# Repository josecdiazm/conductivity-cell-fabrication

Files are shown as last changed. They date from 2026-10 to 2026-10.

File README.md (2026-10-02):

# Conductivity Cell Fabrication

Fabrication resources for ionic conductivity cells, covering both manual (by-hand) construction and PCB-based fabrication.

| In-plane cell (hand) | In-plane cell (PCB) | Through-plane cell (PCB) |
|---|---|---|
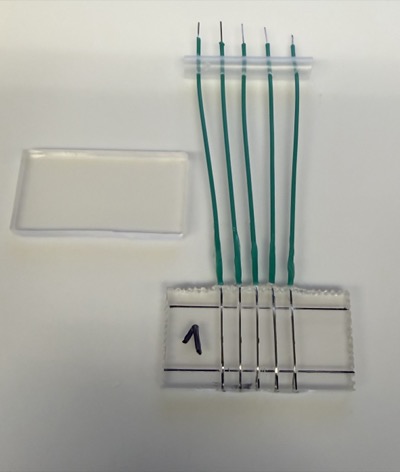
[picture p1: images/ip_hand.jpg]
In-plane cell, hand-fabricated
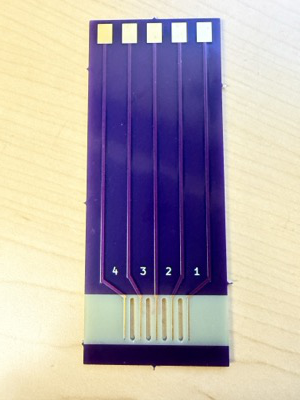
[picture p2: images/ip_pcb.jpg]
In-plane cell, PCB
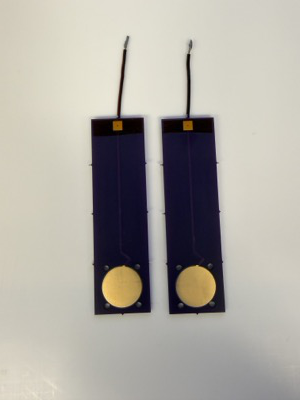
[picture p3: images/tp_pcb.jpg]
Through-plane cell, PCB
|  |  |  |

## Contents

- `manuals/Fabrication_Manual_for_In_Plane_Ionic_Conductivity_Cell.pdf` — step-by-step manual for fabricating in-plane ionic conductivity cells by hand.
- `manuals/KiCad_for_Conductivity_Cell_Design.pdf` — manual for designing and fabricating conductivity cells as PCBs using KiCad.
- `pcb_designs/TP_cell/` — KiCad project and gerber files for the through-plane (TP) cell design.
- `pcb_designs/IP_cell_long-holes/` — KiCad project and gerber files for the in-plane (IP), long-holes cell design.

## PCB designs

Each folder under `pcb_designs/` contains the full KiCad project (`.kicad_pro`, `.kicad_pcb`, `.kicad_sch`) plus a `gerber`/`gerbers` folder with manufacturing files ready to submit to a PCB fab.

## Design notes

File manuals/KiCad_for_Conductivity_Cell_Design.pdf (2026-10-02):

## KiCad for Conductivity Cell Design

José Díaz-Milhet, PhD
Postdoc at MWET (UT Austin) and LBNL-ALS

October 2, 2026

Printed circuit boards (PCBs) make excellent, inexpensive and highly reproducible electrode substrates for electrochemical measurements: the electrode geometry is defined by lithography to within tens of micrometers, the exposed pads can be gold-plated, and a batch of identical cells costs a few dollars. This guide shows how to download and install KiCad, a free and open-source PCB design suite, explains the handful of concepts needed to draw a simple electrode board, and walks through two worked examples: a through-plane and an in-plane cell for measuring the ionic conductivity of membranes.

## Contents

1 Why Use a PCB as an Electrochemical Cell? | 2
2 Downloading and Installing KiCad | 2
3 PCB Primer | 2
4 Step by Step Small Workflow | 4
5 Example 1: Through-Plane Conductivity Cell | 5
6 Example 2: In-Plane Conductivity Cell | 6
7 Ordering Boards | 7
8 Further Reading | 8

## 1 Why Use a PCB as an Electrochemical Cell?

A conductivity cell needs electrodes of accurately known geometry, a rigid flat support and reliable connections to the potentiostat. A PCB provides all three:

- Defined geometry. Electrode area and spacing—the quantities that enter the cell constant—are set by the manufacturer’s photolithography, not by hand.
- Inert surface. With an ENIG (electro-less nickel immersion gold) finish, all exposed copper is covered by nickel and a thin layer of gold.
- Built-in insulation. The solder mask covers the traces, so only the electrode and the contact pad touch the sample or the clips.
- Low cost and reproducibility. Boards are ordered in batches, so every lab member, or every collaborating lab, can use an identical cell.

KiCad is well suited to this job because it is free, runs on Windows, macOS and Linux, and its native files are accepted directly by several board manufacturers.

## 2 Downloading and Installing KiCad

KiCad is distributed from its official site, https://www.kicad.org/download/. Always download from there. This guide was written for KiCad 10 (version 10.0.6, the stable release in October 2026); versions 8 and 9 look and behave almost identically.

First launch. KiCad asks whether to import settings from an earlier version or start with defaults (choose defaults on a new machine), and how to set up the global symbol and footprint library tables. Choose the recommended option, which copies the default tables, so that the standard libraries (including the mounting-hole footprints used below) are available.

## 3 PCB Primer

### 3.1 The project manager and its tools

Opening KiCad shows the project manager. A project is a folder containing a project file (.kicad_pro), a schematic (.kicad_sch) and a board layout (.kicad_pcb). The tools that matter here are:

Tool | What it is for
PCB Editor | Drawing the physical board: outline, copper, mask openings, holes. This is where
almost all the work for an electrode board happens. Footprint Editor Creating reusable pads and holes (e.g. a disc electrode or a slot) that can be placed on any board.
Schematic Editor | Drawing the electrical circuit. Optional for a simple electrode board (Section 4.1).
Gerber Viewer | Checking the exported manufacturing files before ordering.

### 3.2 Layers

A board is described as a stack of layers, selected in the Appearance panel on the right of the PCB Editor. Whatever you draw goes on the active layer (marked by a small arrow in the list). Only a few layers matter for an electrode board (Table 1 and Fig. 1).

Table 1: The layers used for an electrode board.

Layer | Meaning
F.Cu, B.Cu | Copper on the front and back. Pads, electrodes and tracks.
F.Mask, B.Mask | Solder mask. Negative: a shape drawn here is an opening in the
| mask, i.e. exposed (gold-plated) metal.
Edge.Cuts | Board outline and internal cut-outs. Must be closed shapes.
F.Silkscreen, B.Silkscreen | Printed labels (electrode numbers, version, date).
User.Drawings, User.Comments | Notes and dimensions for yourself; not manufactured.

FR4 substrate, ≈1600 µm (1.6 mm)

exposed pad
Cu ≈35 µm
+ Ni 3–6 µm
+ Au 0.05–0.1 µm

solder mask
≈15–25 µm

track
Cu ≈35 µm,
under mask

silkscreen
≈20 µm

Figure 1: Cross-section of a board (not to scale) with typical layer thicknesses for a standard 1 oz copper, ENIG-finished board. The solder mask covers everything except where a shape has been drawn on the mask layer; the surface finish is applied only to exposed copper. Exact values vary by manufacturer.

### 3.3 Units and grid

Work in mm: toggle units with the mm button on the left toolbar or Ctrl + U . Choose a grid from the drop-down list in the top toolbar (e.g. 0.5 mm); everything you draw snaps to it, which makes symmetric layouts easy. The status bar at the bottom shows the absolute cursor position and the distance (dx, dy, dist) from a local origin that you reset by pressing Space . This is the quickest way to measure electrode spacing.

### 3.4 Exact dimensions come from the Properties dialog

Do not try to draw to exact size with the mouse. Draw the shape approximately, select it, press E and type the exact coordinates, sizes and line widths.

### 3.5 Pads belong to footprints

In KiCad a pad (a piece of copper with a matching mask opening, optionally with a hole) lives inside a footprint. For an electrode board there are two ways to make an electrode:

1. Footprint route (recommended for reuse). In the Footprint Editor, create a new footprint containing one surface-mount pad of the required shape and size, enabled on F.Cu and F.Mask only (untick F.Paste). Place it on the board with A .
2. Graphic route (quickest). In the PCB Editor, draw a filled circle or rectangle on F.Cu, then an identical shape on F.Mask to expose it.

## 4 Step by Step Small Workflow

### 4.1 Do I need a schematic?

Short answer, NO! You can just open the PCB Editor and draw directly. The price is that KiCad does not know which pads are meant to be connected, so you must check connectivity by eye. For anything with components (connectors, resistors, sensors), draw a schematic first and use Tools ▶ Update PCB from Schematic.

### 4.2 Steps

1. Create the project. In the project manager, File ▶ New Project. Open the .kicad_pcb file to start the PCB Editor.
2. Set the manufacturer’s limits. File ▶ Board Setup ▶ Design Rules ▶ Constraints. Enter the minimum track width, clearance and hole size of the manufacturer you intend to use (Section 7), so that the design-rule check is meaningful.
3. Draw the board outline. Make Edge.Cuts the active layer and draw a rectangle with the rectangle tool on the right toolbar. Set its exact size with E . The outline must be a single closed shape.
4. Add the electrodes and contact pads. Use either route from Section 3.5. Contact pads should be large enough for your clip or spring-loaded pin (a few mm square is comfortable).
5. Route the tracks. Make F.Cu active, press X , click on the contact pad, click at each corner, and finish on the electrode. Set the track width from the drop-down list in the top toolbar. Tracks are covered by solder mask automatically. Wider tracks have lower resistance; for impedance work there is no reason to use the minimum width.
6. Open the mask where metal must be exposed. Pads made as footprints already have openings. For a larger window (for example over a set of line electrodes), draw a filled rectangle on F.Mask.
7. Add holes and slots. For bolt or alignment holes, press A and place a footprint from the MountingHole library. For long holes, see the box below.
8. Label the board. Make F.Silkscreen active and add text (electrode numbers, cell name, version, date). Future users will thank you.
9. Check. Run Inspect ▶ Design Rules Checker and fix any errors. Then look at the board in View ▶ 3D Viewer ( Alt + 3 ): exposed metal appears gold, masked areas in the mask color. This is the most reliable way to confirm that the mask openings are where you intended.

Two ways to make a slot

Oval hole (preferred). In the Footprint Editor, add a pad with type NPTH, Mechanical and hole shape Oval, and set the hole length and width. Manufacturers treat this as a proper slot.
Cut-out on Edge.Cuts. Draw a closed shape inside the board outline. It is milled out with the same tool as the board edge, so it cannot be narrower than the tool and its inside corners are rounded.

## 5 Example 1: Through-Plane Conductivity Cell

Figure 2 shows the layout TP_cell. The board carries a single disc electrode connected by one track to a square contact pad at the opposite end; four holes surround the disc. Two such boards are placed face to face with the membrane clamped between the discs (Fig. 3).

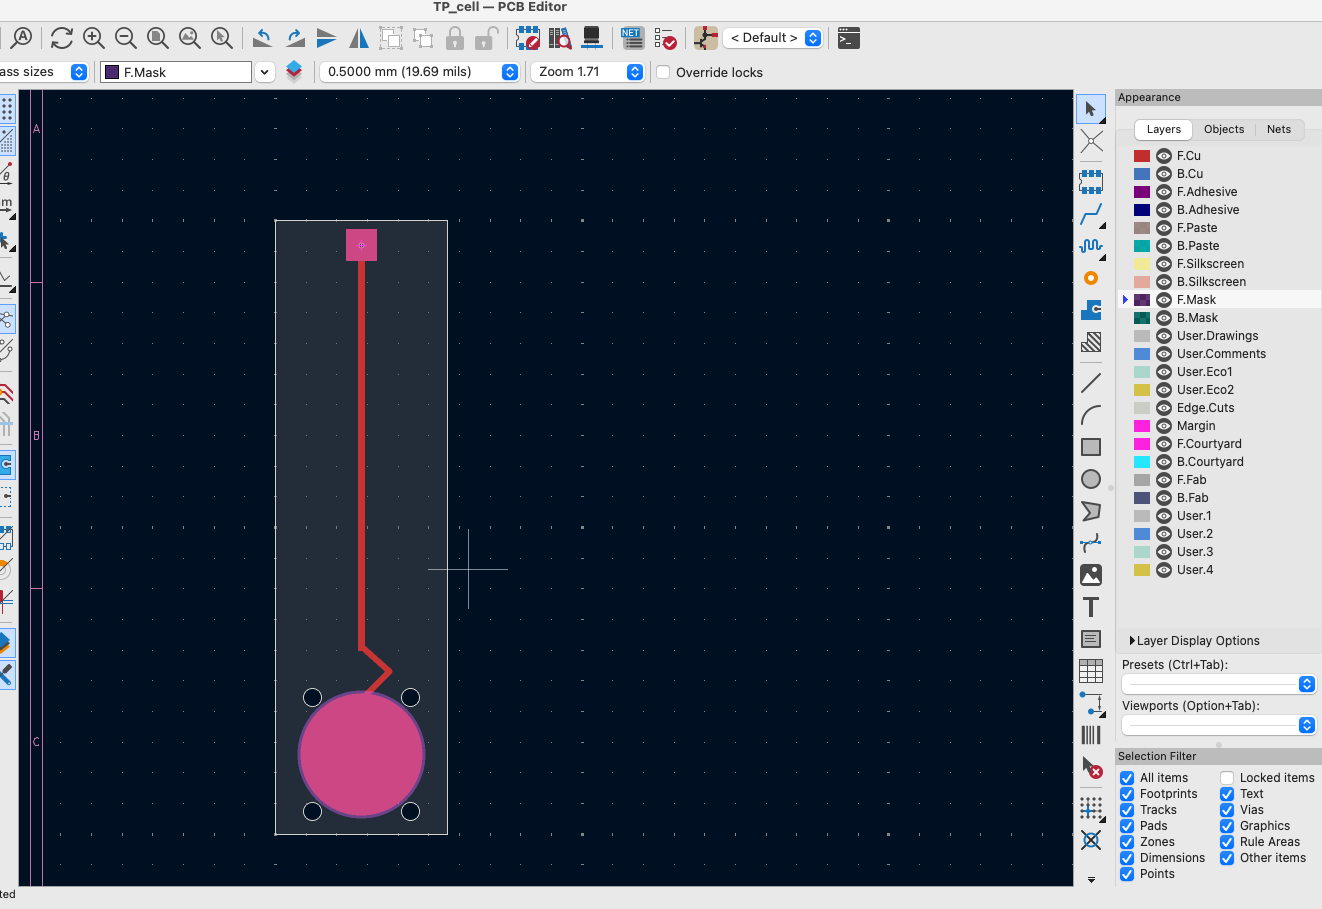
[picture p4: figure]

Figure 2: Through-plane cell (TP_cell) in the KiCad PCB Editor with F.Mask as the active layer. The disc electrode and the square contact pad are exposed (mask openings over copper); the track between them is covered by solder mask.

How it was built in KiCad.

- Edge.Cuts: one rectangle, 28 × 100 mm.
- F.Cu + F.Mask: a circular pad of diameter 2.0 cm (the electrode) and a square pad of side 5.0 mm (the contact).
- F.Cu: one track of width 1.0 mm joining them, with a 45◦ bend to enter the disc.
- Four holes of diameter 2.8 mm around the disc, used for alignment pins.

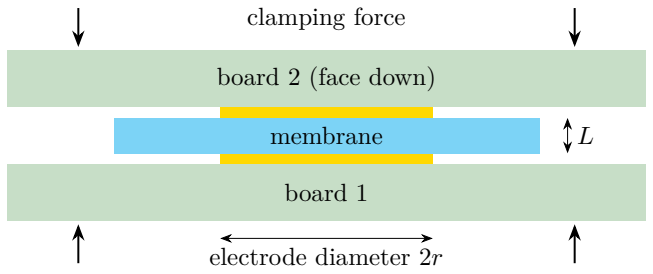
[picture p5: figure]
membrane; board 1; board 2 (face down); electrode diameter 2r; clamping force

Figure 3: Cross-section of the assembled through-plane cell (not to scale).

## 6 Example 2: In-Plane Conductivity Cell

Figure 4 shows the layout IP_cell_long-holes. Five contact pads along the top edge are connected by five tracks to parallel line electrodes at the bottom of the board. The line electrodes sit inside a rectangular solder-mask window, and four long slots, labeled 1–4 on the silkscreen, are cut through the board between them. The membrane is laid across the electrodes (Fig. 5).

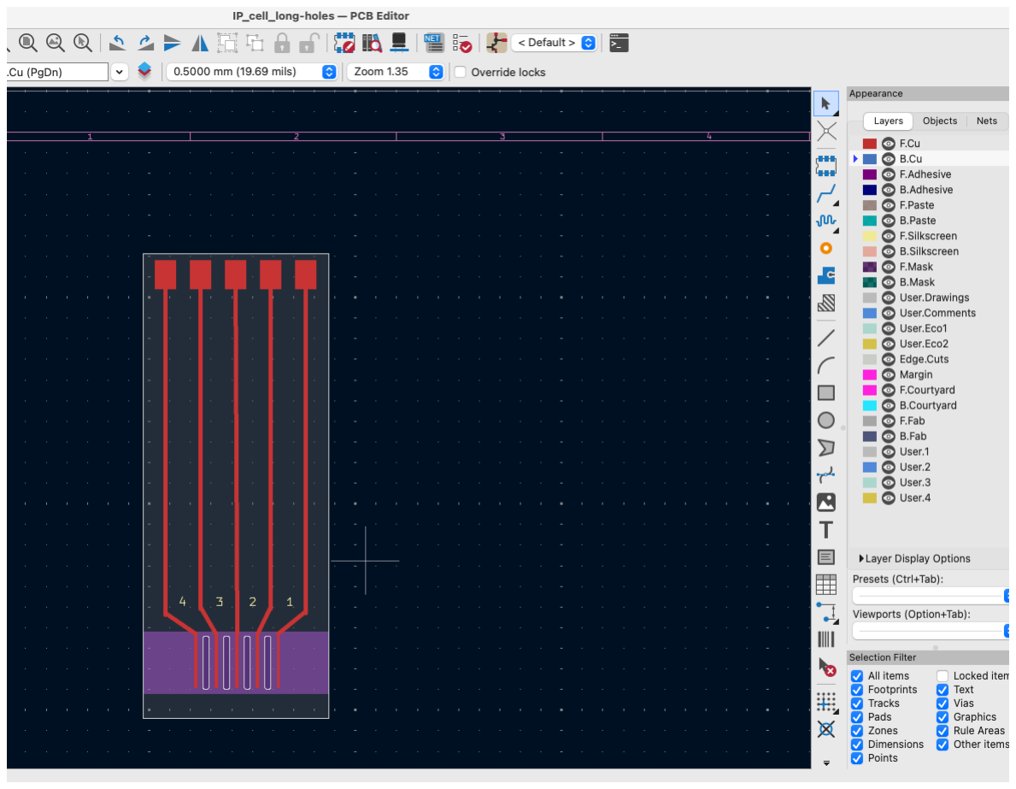
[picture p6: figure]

Figure 4: In-plane cell (IP_cell_long-holes) in the KiCad PCB Editor. The shaded rectangle at the bottom is the mask opening that exposes the line electrodes; the rounded outlines between the electrodes are slots through the board.

How it was built in KiCad.

- Edge.Cuts: one rectangle, 45 mm × 112.5 mm.
- F.Cu + F.Mask: five rectangular contact pads, 5.0 mm wide and 7.0 mm high.
- F.Cu: five tracks of width 1.0 mm, running straight down and then converging at 45◦
to a
center-to-center spacing of 5.0 mm. The lower ends of the tracks are the electrodes.
- F.Mask: one filled rectangle over the electrode region, so the tracks are exposed (and gold-plated) only there.
- Four slots, 1.5 mm × 13 mm, between adjacent electrodes to let water reach both faces of the membrane between the electrodes.
- F.Silkscreen: the numbers 1–4.

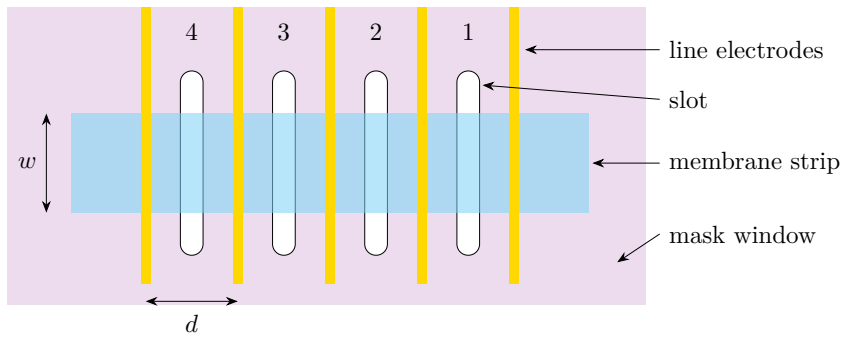
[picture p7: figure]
line electrodes; slot; membrane strip; mask window

Figure 5: Top view of the electrode region of the in-plane cell with a membrane strip of width w laid across the electrodes (not to scale). d is the distance between two electrodes.

## 7 Ordering Boards

### 7.1 What every manufacturer needs

Any board house can make these cells from a set of Gerber files (one per layer) plus drill files:

1. File ▶ Fabrication Outputs ▶ Gerbers (.gbr).
2. Tick the layers F.Cu, B.Cu, F.Mask, B.Mask, F.Silkscreen, B.Silkscreen and Edge.Cuts; choose an output folder; click Plot.
3. In the same dialog click Generate Drill Files and generate them into the same folder.
4. Open the folder in the Gerber Viewer and check each layer, especially the mask openings and the slots.
5. Compress the folder to a .zip file and upload it to the manufacturer.

### 7.2 Choices that matter for electrochemistry

- Surface finish: choose ENIG. The default at many manufacturers is HASL (tin or tin– lead solder), which is unsuitable as an electrode surface. ENIG gives gold over nickel on all exposed copper.
- Board thickness. 1.6 mm is standard and rigid enough to clamp.
- Solder-mask color. Cosmetic; any color insulates the tracks.
- Quantity. Minimum orders are typically three to five boards.

The gold layer is thin

The immersion gold of an ENIG finish is on the order of 0.1 µm thick, over a few micrometers of nickel. It is adequate for contact-type impedance measurements on hydrated membranes, but it is porous and wears with repeated clamping, and the nickel beneath can corrode under sustained polarization or in aggressive electrolytes. Inspect the electrodes periodically and replace boards that look dull or pitted. Some manufacturers offer thicker or hard gold at extra cost.

### 7.3 Example: OSH Park

The cells in this guide were made by OSH Park (https://oshpark.com), which is convenient for small batches. At the time of writing, its two-layer prototype service has the specifications below:

Item | Value
Price | $5 per square inch, for three copies
Quantity | Multiples of three
Surface finish | ENIG (gold), standard
Solder mask | Purple
Thickness, copper | 1.6 mm FR4, 1 oz copper per layer
Minimum track width and spacing | 6 mil (0.15 mm)
Minimum drill | 10 mil (0.25 mm)
Edge keep-out for copper | 15 mil (0.38 mm)
Minimum cut-out | 0.068 in (1.7 mm); cut-outs are not plated
Turnaround | Ships in 9–12 calendar days

Uploading. OSH Park accepts either a zip of Gerber and drill files or the KiCad .kicad_pcb file itself, which saves the export step. Two caveats apply to direct upload:

- The file is opened with OSH Park’s own installed KiCad version (9.x at the time of writing). A board saved by a newer KiCad may not open; in that case upload Gerbers.
- Silkscreen text may change font unless fonts are embedded in the board file (Board Setup ▶ Embedded Files ▶ Embed Fonts).

After upload, the website shows a rendering of every layer. Check the mask openings and slots there before paying: it is the last chance to catch a mistake.

### 7.4 Other manufacturers

The same Gerber zip works with any other board house (for example JLCPCB, PCBWay or Eurocircuits, or a local supplier). When ordering elsewhere: 1) select ENIG explicitly, since it is usually an option rather than the default; 2) enter that manufacturer’s limits in Board Setup and rerun the design-rule check, since minimum track, hole and slot sizes differ; 3) check how slots and cut-outs must be specified, since conventions vary.

## 8 Further Reading

- KiCad download page: https://www.kicad.org/download/ and documentation, including “Getting Started in KiCad”: https://docs.kicad.org
- OSH Park documentation (KiCad uploads, two-layer service, board outline rules): https: //docs.oshpark.com
- J. C. Díaz and J. Kamcev, “Ionic conductivity of ion-exchange membranes: Measurement techniques and salt concentration dependence,” Journal of Membrane Science, 618, 118718 (2021). doi:10.1016/j.memsci.2020.118718 (https://doi.org/10.1016/j.memsci.2020.118718)
- J. C. Díaz, D. Kitto and J. Kamcev, “Accurately measuring the ionic conductivity of membranes via the direct contact method,” Journal of Membrane Science, 669, 121304 (2023). doi:10.1016/j.memsci.2022.121304 (https://doi.org/10.1016/j.memsci.2022.121304)

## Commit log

2026-10-02 Initial commit: conductivity cell fabrication manuals and PCB designs
    Adds hand-fabrication and KiCad-PCB-fabrication manuals plus the TP_cell
    and IP_cell_long-holes KiCad projects with gerber files.
    [IP_cell_long-holes-B_Cu.gbr, IP_cell_long-holes-B_Mask.gbr, IP_cell_long-holes-B_Silkscreen.gbr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]
2026-10-04 Update in-plane cell PCB photo
2026-10-04 Resize in-plane cell PCB photo for README table layout
2026-10-04 Update through-plane cell PCB photo
